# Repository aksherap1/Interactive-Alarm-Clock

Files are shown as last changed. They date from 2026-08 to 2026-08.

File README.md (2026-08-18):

# Interactive Robotic Alarm Clock

Screenshot 2026-08-17 at 5 17 38 PM

An expressive 6-DOF robotic alarm clock designed in Onshape, engineered for rapid FDM/SLA prototyping, and powered by an ESP32-S3 custom PCB. The character wakes users up using biomimetic kinematic motion and personality states prior to audio alarms.

**CAD Model:** [View Onshape 3D Assembly](https://cad.onshape.com) *(Insert Onshape Public Link)*  
**Author:** Akshera Paladhi  
**Date:** August 15, 2026  

---

## Overview & Emotional States

The robot uses physical gestures and lighting to communicate status before audio triggers:

- **Sleeping:** Head slouches forward/down, ears droop, and ambient LEDs slowly breathe with a dim, soft light.
- **Waking Up:** Head lifts smoothly, pans to face the user, and ears perk up.
- **Alarm Active:** Head aligns directly with the user, ears flap straight back, ambient LEDs pulse, and I2S audio begins.
- **Snooze:** Hitting the top snooze button causes the head to drop back into a slouch while the ears relax into rest mode.

---

## Kinematics & Motion (6-DOF)

The mechanical assembly uses daisy-chained **FeeTech SCS0009** serial micro-servos to minimize wiring harnesses across moving joints:

| Articulation Stage | DOFs | Range of Motion | Mechanical Function |
| :--- | :---: | :--- | :--- |
| **Head Base (Yaw)** | 1 | 330° | Panning rotation to scan and face user |
| **Head Pivot (Pitch/Roll)** | 1 | 180° | Nodding and expressive tilting |
| **Left Ear (Yaw + Pitch)** | 2 | 330° Yaw, 180° Pitch | Independent perking, swivel, and drooping |
| **Right Ear (Yaw + Pitch)** | 2 | 330° Yaw, 180° Pitch | Independent perking, swivel, and drooping |

---

## Design for Manufacturing & Assembly (DFM / DFA)

The enclosure splits into 9 modular parts designed for supportless 3D printing and tool standardization:
- **Modular Breakdown (9 Printed Parts):**
  1. `Clock Main Base`: 6.50" x 4.63" x 0.50" octagon with filleted corners to eliminate warping; built-in pass-through slots for wiring.
  2. `Clock Cover Base`: Flat front bezel with 3.0" circular display cutout; prints flat with zero support material.
  3. `Clear Case (Screen Lens)`: Drop-in transparent PETG protective lens.
  4. `Battery Pack Cover`: Clamping plate securing a 2x 18650 sled with two accessible fasteners.
  5. `Ears (x2)`: Dual Mickey-style ear paddles with direct servo horn mounting brackets.
  6. `Box Servos (x2)`: Keyed cutouts holding the vertical yaw servo bodies.
  7. `Three Box (x3)`: Structural rectangular housings linking the pitch/yaw servos.
  8. `Bottom Chassis`: Wide footprint housing the main vertical yaw servo to keep the center of mass low.
  9. `Bottom Chassis Cover`: Underside access plate for servicing batteries and the base servo.
- **Hardware Standardization:** Standardized on M2 machine screws (0.177" clearance pockets) paired with M2 brass heat-set inserts melted into 5.0 mm deep standoffs. The entire assembly requires only a single 1.5 mm hex driver.

---

## Electronics & Custom 2-Layer PCB

The internal board separates user-facing interfaces from high-current power stages:

### Front Side (User-Facing)
- 3.0-inch circular SPI/RGB display module
- 3x Tactile push buttons (Snooze, Alarm Set, Reset/Boot)
- WS2812B addressable RGB LEDs for diffused ambient lighting

### Back Side (Power & Logic)
- **MCU:** ESP32-S3 dual-core microcontroller
- **Power Management:** AMS1117 3.3V LDO regulator + TP4056 lithium battery charger (2x 18650 Li-ion cells)
- **Audio Stage:** MAX98357A I2S audio amplifier driving a mini speaker
- **Connectivity:** JST-PH connectors for daisy-chained servos and battery power
- **Signal Integrity:** Solid copper ground plane on Layer 2 to isolate motor noise; 4.7kΩ pull-up resistors on active-low tactile lines

---

## Engineering Calculations & Validation

### 1. Neck Tilt Servo Torque Margin
```text
Torque Equation:
  τ_req = (m * g * r) * S

Variables:
  m = 0.165 kg (Head assembly: housing, LCD, PCB, hardware)
  g = 9.81 m/s²
  r = 0.048 m (Distance to Center of Mass)
  S = 1.5 (Safety Factor)

Calculation:
  τ_req = (0.165 kg * 9.81 m/s² * 0.048 m) * 1.5
  τ_req = 0.116 N·m ≈ 1.19 kg·cm

Validation:
  FeeTech SCS0009 stall torque @ 6V = 2.30 kg·cm
  Factor of Safety (FoS) = 2.30 / 1.19 = 1.93 (Stall-free continuous operation)
Stress Equation:
  σ = (M * c) / I

Parameters:
  Applied Load = 30 N (~6.7 lbf downward impact)
  Max Bending Stress (σ) = 14.2 MPa
  PETG Yield Strength (σ_y) = 45.0 MPa

Validation:
  Factor of Safety (FoS) = 45.0 / 14.2 = 3.17 (Safe against fatigue impact)
[ Weeks 1-4: EVT / Proto ] ──> [ Weeks 5-12: EVT / Validation ] ──> [ Weeks 13-20: DVT ] ──> [ Weeks 21-26: PVT / Launch ]
  • CAD kinematic check         • Mold draft angles & bosses        • Tooling & steel molds     • First-article inspection
  • 3D print load testbench     • 1m drop testing on wood           • 100k-cycle joint life     • Work instructions & SOPs
  • 2-layer PCB layout          • Wire harness fatigue cycling      • Acoustic dampening tune   • Final packaging & release

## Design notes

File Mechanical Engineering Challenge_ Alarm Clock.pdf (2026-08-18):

Akshera Paladhi

August 15, 2026

# Mech Challenge Documentation: Alarm Clock

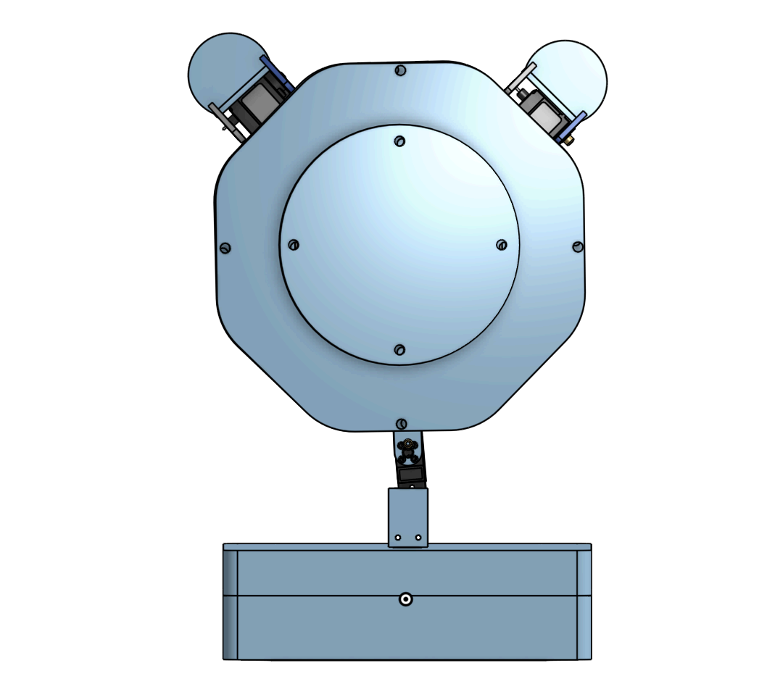
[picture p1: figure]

# Deliverables

CAD Model Link: Onshape Design (https://cad.onshape.com/documents/98c9af075805dfa337587d56/w/5debba2be09580806e3426c2/e/b373fb9812e17f7dab6772cc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)

## Design Overview & Decision Matrix

For this challenge, I wanted to turn the clock into an expressive little robot character that wakes you up using natural motion and personality before it makes somes sound.

The character has these emotional states:

1

- Sleeping: The head slouches forward/down slightly, the ears droop, and the ambient LEDs slowly breathe with a dim, soft light.
- Waking Up: The head slowly lifts up and pans smoothly to face you, and the ears perk up.
- Alarm Going Off: The head looks straight at you, the ears flap back straight, and the alarm audio begins to play.
- Snooze: When you hit the snooze button on top, the head drops back into a slouch, the ears fall backward, and it goes back to resting.

How It Moves (6 Degrees of Freedom Total)
To make the character feel alive without making the wiring a total mess, I used FeeTech SCS0009 micro servos daisy-chained together to get 6 total DOFs:
- The Head (2 DOFs):
- Spin / Yaw: The main base turns up to 330 degrees around so it can look left, right, forward, and almost all the way behind itself.
- Tilt / Nod (Pitch/Roll): Tilts side-to-side and up-and-down to show curiosity or look like it's nodding.
- The Ears (4 DOFs — 2 on each ear):
- Left Ear: Spins around 330 degrees (Yaw) and flaps front-to-back 180 degrees (Pitch).
- Right Ear: Spins around 330 degrees (Yaw) and flaps front-to-back 180 degrees (Pitch).

Why I Chose This Design?

When I started designing, I thought through three different directions:

### 1. Option 1: Just a Fixed Screen in a Box (Like an Echo Show)

- Problem: It would be super easy to 3D print and assemble, but it has zero character or physical life. It completely misses the point of the challenge.

### 2. Option 2: A Screen with 1 Simple Nodding Motor

- The Problem: Adding just one motor lets the screen tilt up and down, but that's really only one gesture (nodding). It still feels like a generic appliance with a hinge.

2

### 3. Option 3: Fully Articulated Head & Moving Ears (My Chosen Design)

- Why it won: Putting moving ears on top of a panning head gives you real character expressions (like a curious puppy or Mickey Mouse ears perking up). The main engineering challenge was making sure 6 motors did not turn into a huge mess along with the other wiring as well. By splitting the mechanical enclosure into 9 clean modular parts and designing a custom 2-layer PCB that hides all the motor connections on the back, I was able to get full 6-DOF movement while keeping the assembly clean and straightforward.

## DFM & DFA (How it’s Made & Assembled)

I broke everything into 9 3D printable parts so everything prints without any overhangs and can be put together easily like mentioned.

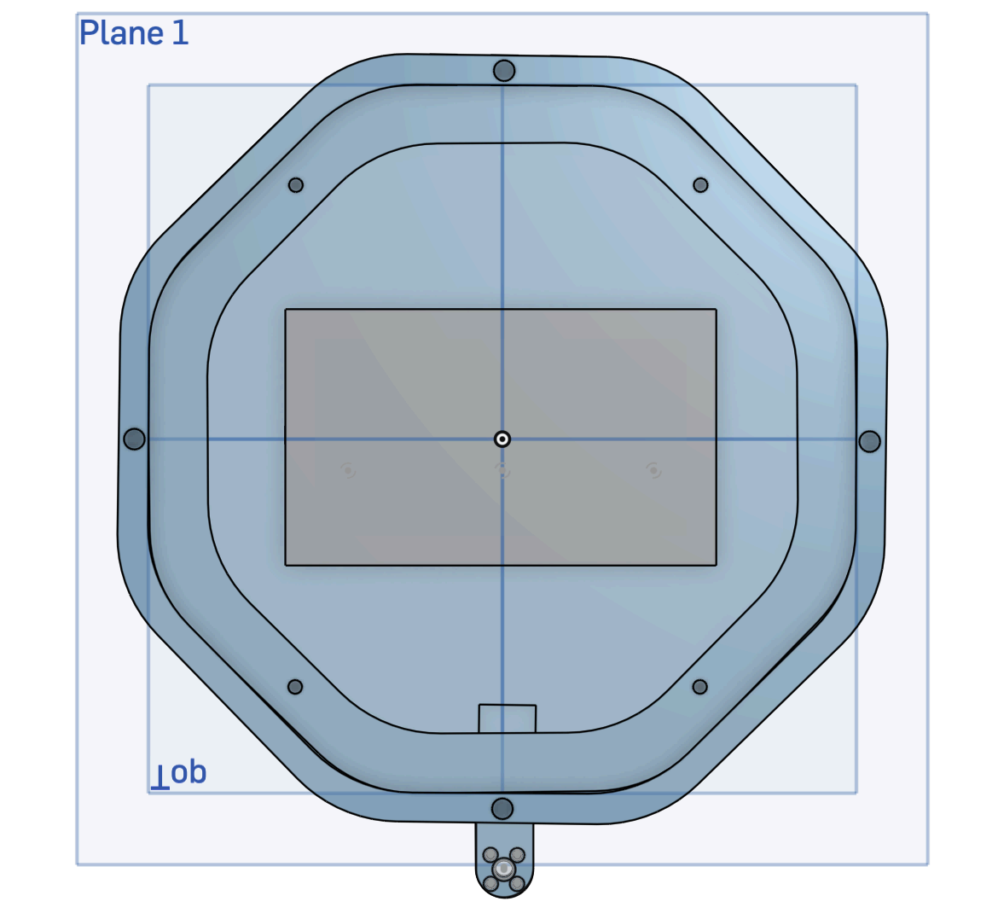
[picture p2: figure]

Clock Main Base

Sized at 6.5 inches wide, 4.63 inches deep, and 0.5 inches face thickness. I made it an octagon with filleted (rounded) corners so it prints cleanly without warping at sharp
edges.It has built-in
rectangular pass-through holes so the red and black power wires slide right through to the back of the PCB without getting pinched.

3

Clock Cover Base | Flat front bezel with a circular cutout for the 3-inch display. Prints flat with zero support material and has alignment screw holes matching the main base.

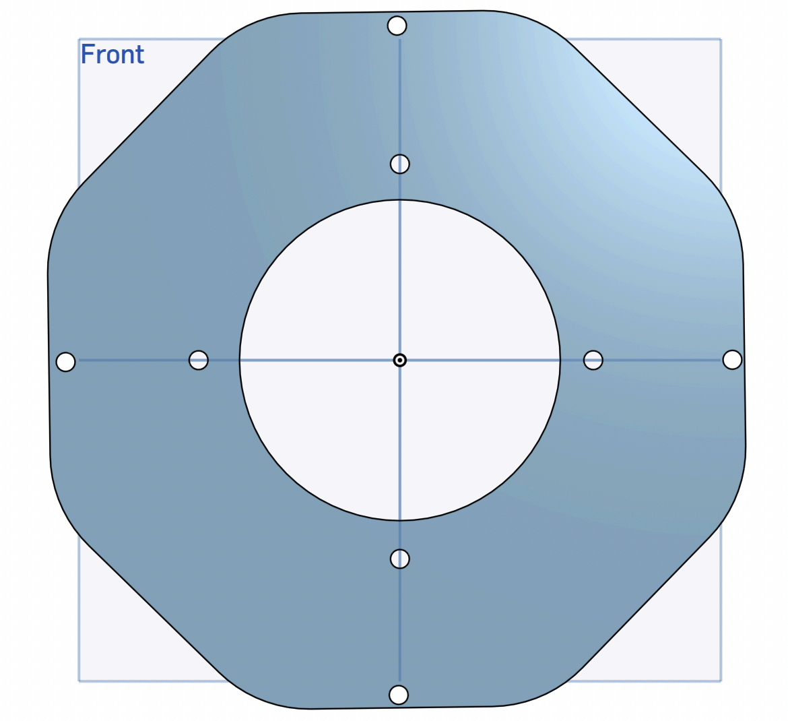
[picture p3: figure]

Clear Case (Screen Lens) | Printed out of transparent filament (Clear PETG) to protect the 3-inches LCD from dust and scratches. Drops right into the front cover bezel without needing messy adhesives.

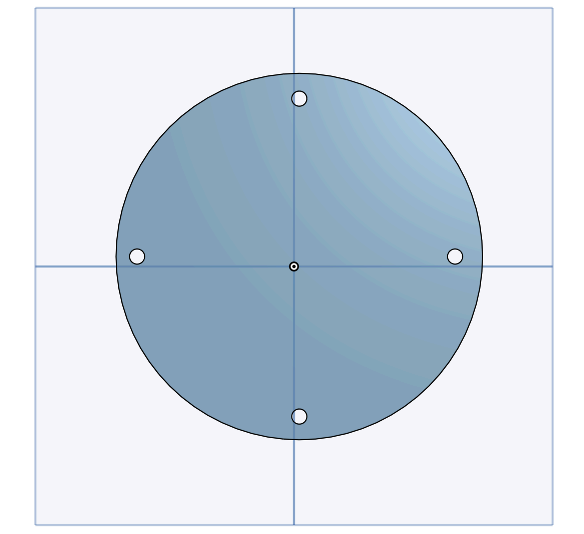
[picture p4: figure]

Battery Pack Cover | A symmetrical clamping plate that secures a standard 2x18650 battery sled inside the base using two quick screws.

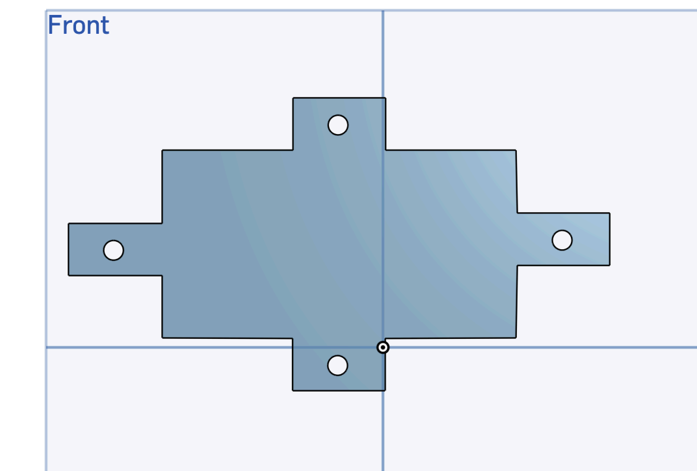
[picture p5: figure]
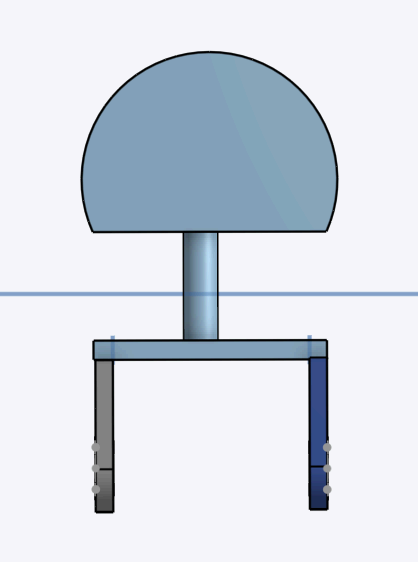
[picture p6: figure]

Two Ears (times 2) | Mickey-mouse shaped ear paddles with built-in mounting brackets. The arms attach directly to the micro servo horns so the ears can flap back and forth without extra linkage parts.

4

Two Box servos (times 2) | Specially keyed cutout that holds the FeeTech SCS0009 servo body securely.This is for the vertical yaw for the ear.

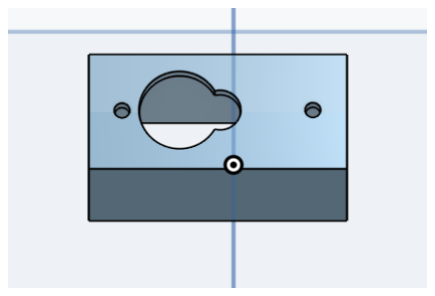
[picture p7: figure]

Three Box (times 3) | A simple rectangular housing that prints straight up without support. Also used to insert another servo in here as well.This is the vertical yaw servo can be attached to the servo that allows the two ears to flap back and forth and the head to go side to side.

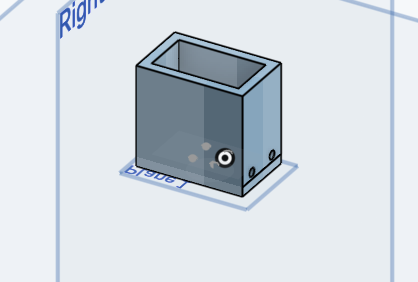
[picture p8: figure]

Bottom Part (Chassis) | Wide, sturdy bottom base that holds the main vertical yaw servo and keeps the center of mass low so the clock doesn't wobble when it turns.

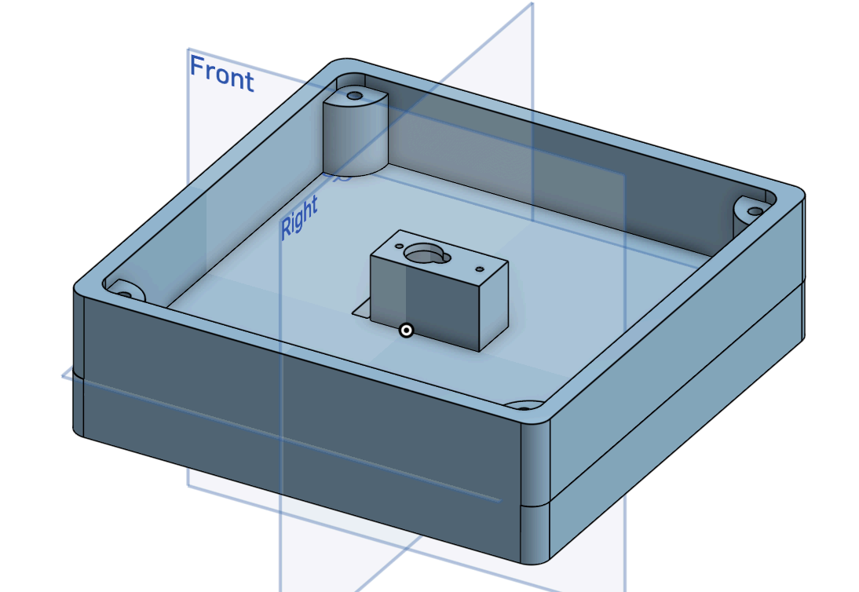
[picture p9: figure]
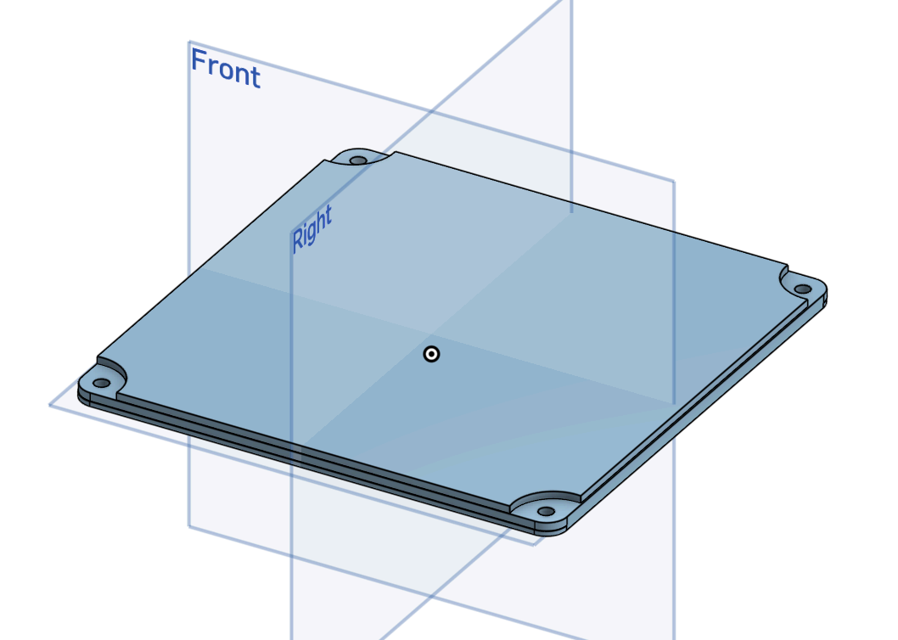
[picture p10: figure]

Bottom Part Cover | Flat plate that seals the bottom base. Screws on from the underside so you can easily access the battery and bottom servo without taking the entire head apart.

Hardware Standardization (DFA): I standardized all mounting hardware to use M2 machine screws 0.177 inches clearance pockets, 0.338 inches paired with M2 brass heat-set inserts melted into

### 5.0 mm deep standoffs.This means you only need one 1.5 hex driver

to build the whole clock, and the brass threads won't strip if

5

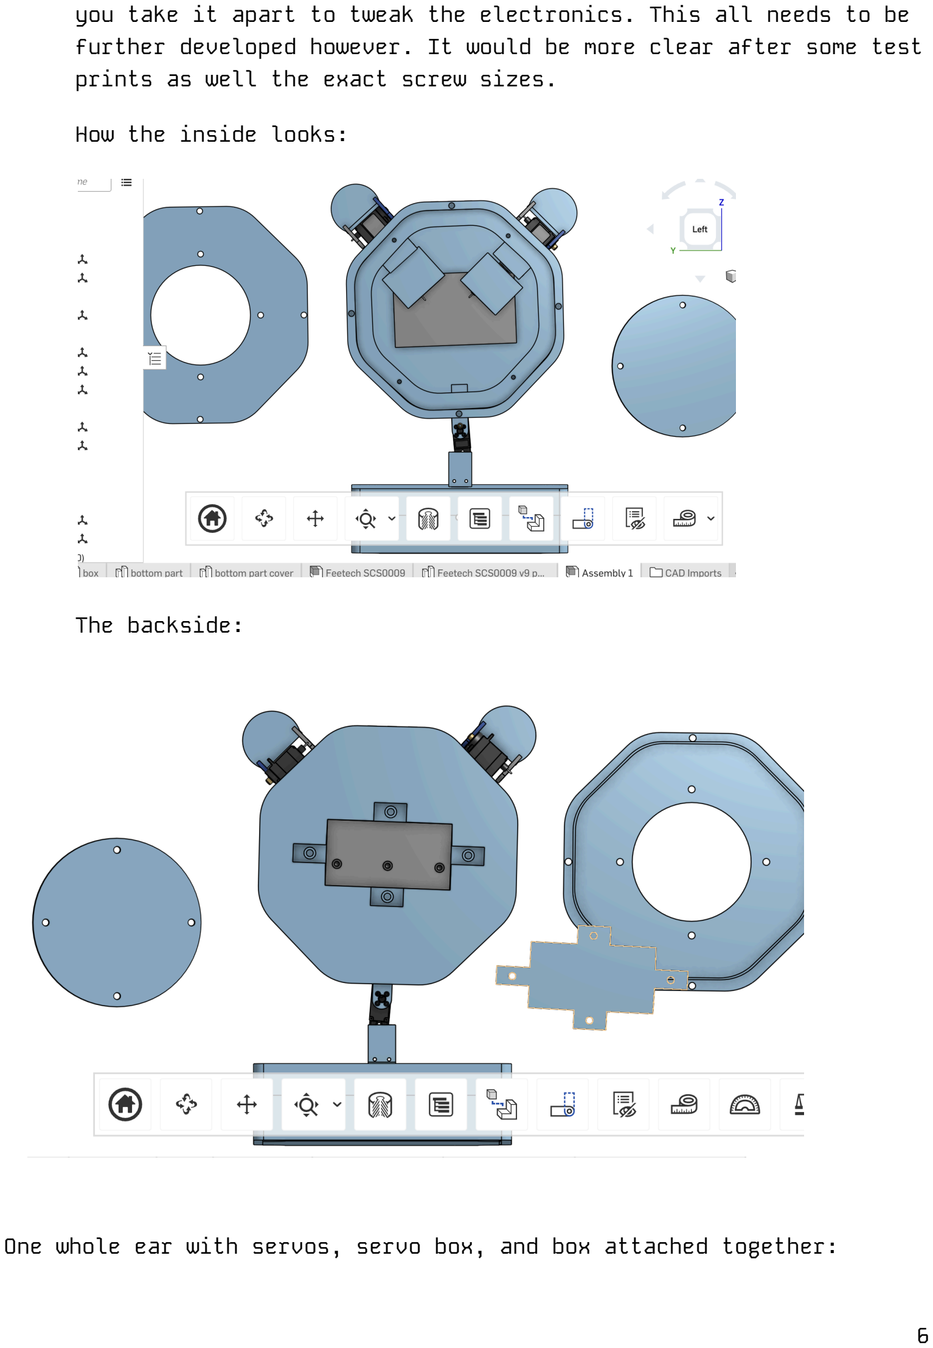
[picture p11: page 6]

you take it apart to tweak the electronics. This all needs to be further developed however. It would be more clear after some test prints as well the exact screw sizes.

How the inside looks:

The backside:

One whole ear with servos, servo box, and box attached together:

6

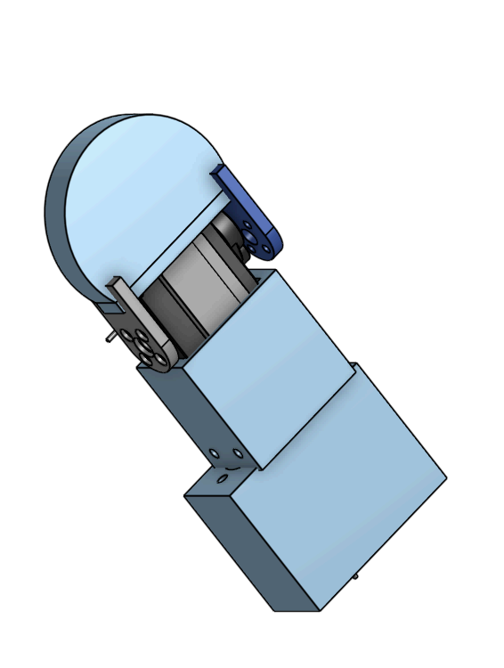
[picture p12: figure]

## Custom 2-Layer PCB Design

I put a custom 2-layer PCB inside the main base to separate the clean user controls on the front from the messy wiring and power circuitry on the back:

PCB layout:

Front Side (What User Sees)
- 3.0 Inches Circular display Screen
- 3 Tactile Push Buttons (Snooze, Alarm Set, Reset/Boot)
- WS2812B RGB LEDs for soft ambient lighting

Back Side (Internal Wiring)
- ESP32-S3 Microcontroller Module
- AMS1117 3.3V Voltage Regulator + TP4056 Battery Charger
- MAX98357A I2S Audio Amp for the speaker
- JST Connectors for daisy-chaining servos & battery pack
- 4.7kΩ Pull-Up Resistors + Power Filtering Capacitors
- Solid Copper Ground Plane to block motor electrical noise

I used 4.7kΩ pull-up resistors (tied to 3.3V) on the buttons and communication lines. When a button is pressed, it pulls the signal line to GND. This gives a reliable active-low trigger and prevents the ESP32 from glitching when the motors draw power.

7

## Engineering Math & Calculations

We need to prove the FeeTech SCS0009 servo has enough torque to lift and tilt the head without stalling:

τ = (m * g * r) * S

- Head Assembly Weight (m): Approximately 0.165 kg (Housing, LCD screen, PCB, hardware)
- Distance to Center of Mass (r): Approximately 4.8 cm/0.048 m
- Safety Factor (S) : 1.5

τ = (0.165 kg *9.81m/s^2 * 0.048 m) * 1.5 = 0.116N * m = 1.19kg * cm

Validation: The FeeTech SCS0009 provides 2.30 kg * cm of
torque at 6V. Since we only need 1.19 kg*cm, we have a Factor
of Safety of approximately 1.93, so the servo will run smooth and won't overheat.
B. Stress Check ("Snooze Slap" Test)
When someone is half-awake and smacks the top snooze button with around 30N of force which is approximately 6.7 lbs.

σ = (M*c)/I

- Maximum calculated bending stress on the pivot mounting boss is σ = 14.2 MPa
- Standard 3D-printed PETG has a yield strength of approximately 45 MPa
- Factor of Safety: 45/14.2 = 3.17 . The plastic structure will easily take repeated morning hits without cracking.
C. Motor Vibration & Heat Management
- Vibration/Acoustics: Small servos can buzz and rattle plastic shells. I would add silicone damping rings between the servo mounts and the printed boxes (Part 7) to mechanically isolate motor chatter and keep the alarm speaker sounding clear.
- Thermal Dissipation: The ESP32 and voltage regulator only pull about 2.5W on average. The cable cutouts in the back provide

8

natural airflow to keep internal temperatures below 55 degrees Celsius without the need of noisy fans.

## Material Choices

- Main Base, Covers & Chassis > PETG: Tougher and more heat-resistant than regular PLA, handles impacts from being slapped, and holds brass heat-set inserts securely without cracking.
- Clear Screen Cover (Part 3) >Transparent PETG / Acrylic: Clear and see-through to protect the LCD screen from dust and scratches.
- Joint Boxes & Brackets >Nylon / PETG: Low-friction and wear-resistant so rotating joints do not wear down or bind over time.
- Vibration Dampers > Molded Silicone Rubber: Soft rubber grommets that absorb motor buzzing and gear vibration.

## Manufacturing Notes & Tolerances (GD&T)

When sending the Clock Main Base (Image 1) to a machine shop or manufacturer,put emphasis on surfaces matter the most and how accurate the cuts need to be:

- What it is made of & how it gets made:
- For the working prototype, it gets 3D printed out of PETG.
- For real mass production, it gets plastic injection molded out of ABS or PETG.
- The Main Flat Mounting Face (Datum A): The back mounting surface must be flat within 0.002 inches so the front cover and internal mounts sit completely flush without wobbling.
- The Center Servo Pivot Hole (Datum B): The main pivot hole needs a snug fit 0.472 inches with a +0.001 / -0.000 inches tolerance) so the servo spline slides in tight without slipping or binding.
- The M2 Screw Holes: The screw hole center positions have a true position tolerance of 0.003 inch relative to Datum A and Datum B so the screws always line up with the brass heat-set inserts.
- Main Face Thickness: The main front wall thickness is maintained at 0.500 inches +/- 0.005 inches (along with the overall 6.50

9

inches width and 3.63 inches depth) so the structural shell holds its shape without sinking or warping.

## Product Launch Roadmap & Engineering Tasks

If I were leading the mechanical design from day one to the launch date, here is the timeline and the main engineering tasks (tickets) to get it built and shipped:
Phase 1: Concept & Prototyping (Weeks 1 to 4)
- Task 1: Finish the 3D model in CAD and check that the head and ears can turn without bumping into each other.
- Task 2: 3D print a quick test rig to test the micro servos under real weight and make sure they don't stall.
- Task 3: Size the custom 2-layer PCB layout so all the electronics fit cleanly inside the head.
Phase 2: Engineering Validation (EVT) (Weeks 5 to 12)
- Task 1: Add draft angles (slight slopes on the walls) and screw bosses into the CAD files so the parts can be injection molded.
- Task 2: Drop-test the 3D-printed body from a desk height of 1 meter onto wood to make sure the plastic doesn't snap.
- Task 3: Run the head back and forth continuously to verify that internal wires don't twist, rub, or wear out.
Phase 3: Design Validation (DVT) (Weeks 13 to 20)
- Task 1: Send the final 2D drawings to the factory to start cutting the steel injection molds.
- Task 2: Run long-term reliability tests on the ears and neck joints (moving them about or more than 100,000 times to check for wear).
- Task 3: Adjust the rubber dampening around the motors so the alarm speaker sounds clear without making the plastic shell rattle.
Phase 4: Production & Launch (PVT) (Weeks 21 to 26)
- Task 1: Inspect the first real batch of molded plastic parts from the factory to make sure dimensions match the drawings.

10

- Task 2: Set up the assembly line steps and write a simple assembly guide for the factory workers.
- Task 3: Run final packaging drop tests, box the units up, and launch the product.

## Future Upgrades & Next Steps

Add a Center Slip-Ring: Right now the head turns 330 degrees so the wires don't wrap up. Adding a small 4-wire slip ring down the center shaft would let the head spin a full continuous 360 degrees.

Capacitive Touch Snooze: Instead of a mechanical push button on top, put a capacitive touch sensor on the inside of the top shell so you can tap anywhere on the head to snooze. This way a user can pet the alarm clock and it can create that more interactive feature.

Organic Motion Curves: Program smooth S-curve bezier acceleration in C + on the ESP32 so the head and ears accelerate and slow down gently like a real living character just like the PIXAR lamp that was created as well.

11

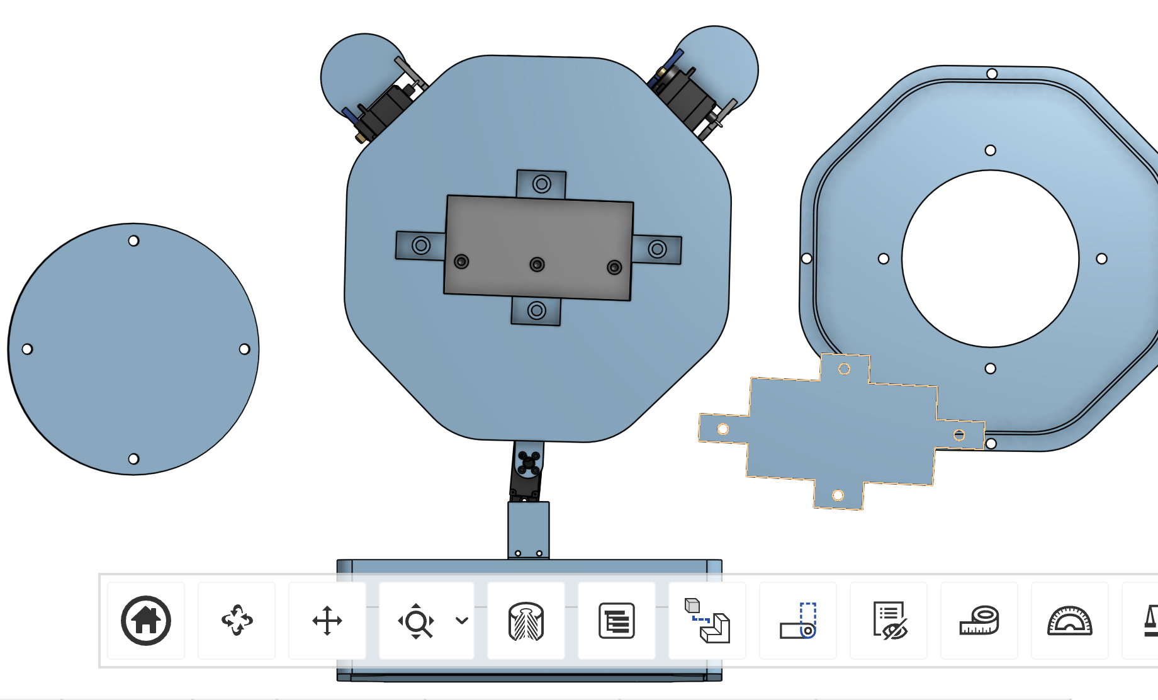
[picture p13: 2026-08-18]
Screenshot 2026-08-15 at 1.11.09 AM.png

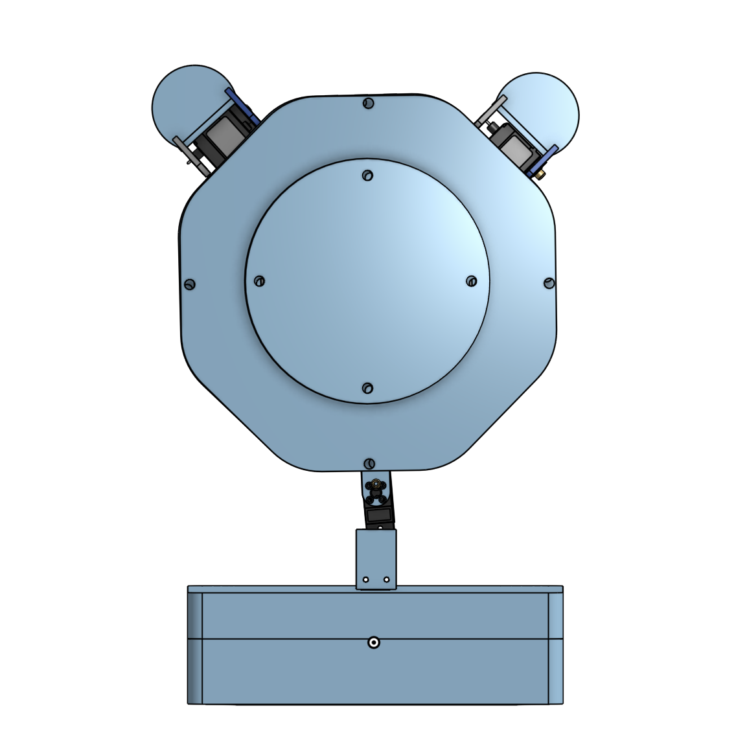
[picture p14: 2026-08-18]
Screenshot 2026-08-17 at 5.17.38 PM.png

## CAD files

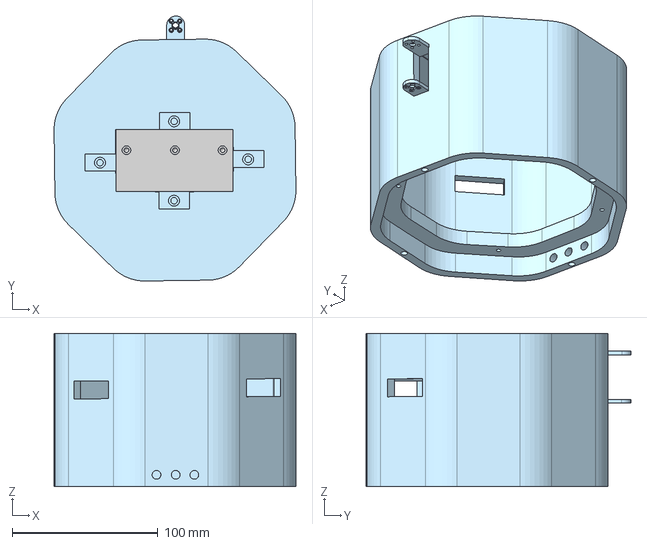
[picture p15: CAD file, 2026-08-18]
clock main base.step
165.7 x 181.5 x 104.9 mm

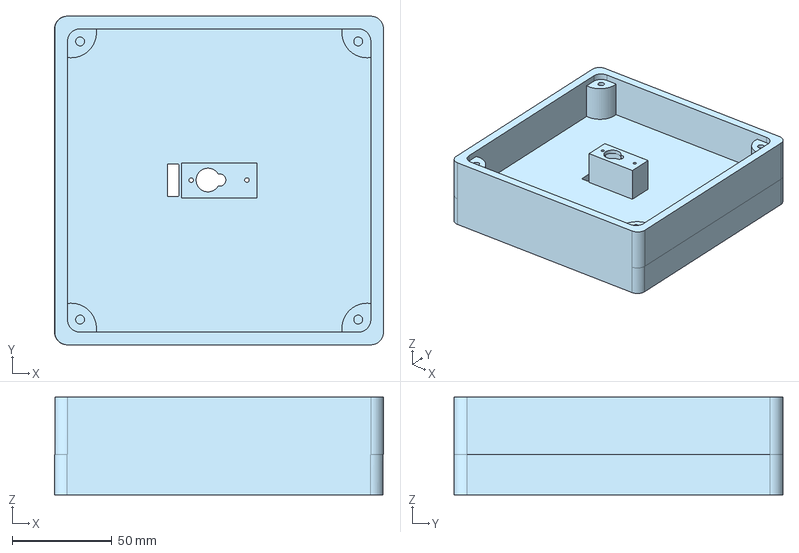
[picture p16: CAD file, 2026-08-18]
bottom part - Part 1.step
165.3 x 165.1 x 49.0 mm

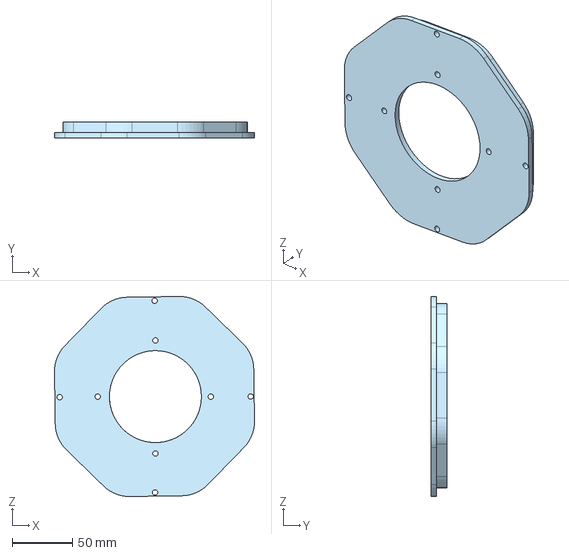
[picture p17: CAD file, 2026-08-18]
clock cover base - Part 1.step
165.7 x 12.9 x 165.7 mm

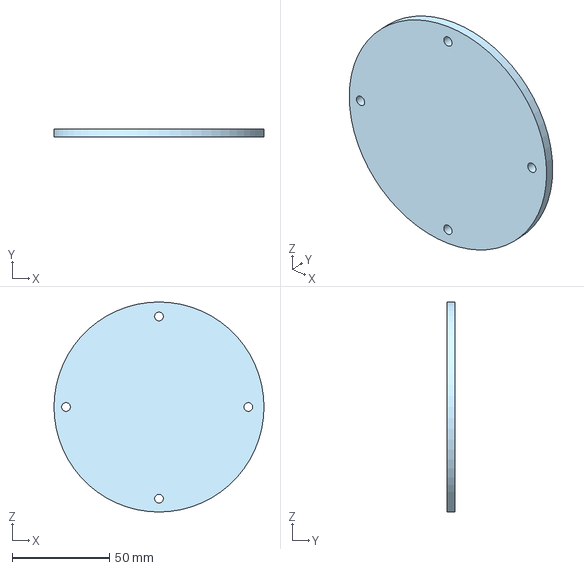
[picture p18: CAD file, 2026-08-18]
clear case - Part 1.step
108.0 x 4.29 x 107.9 mm

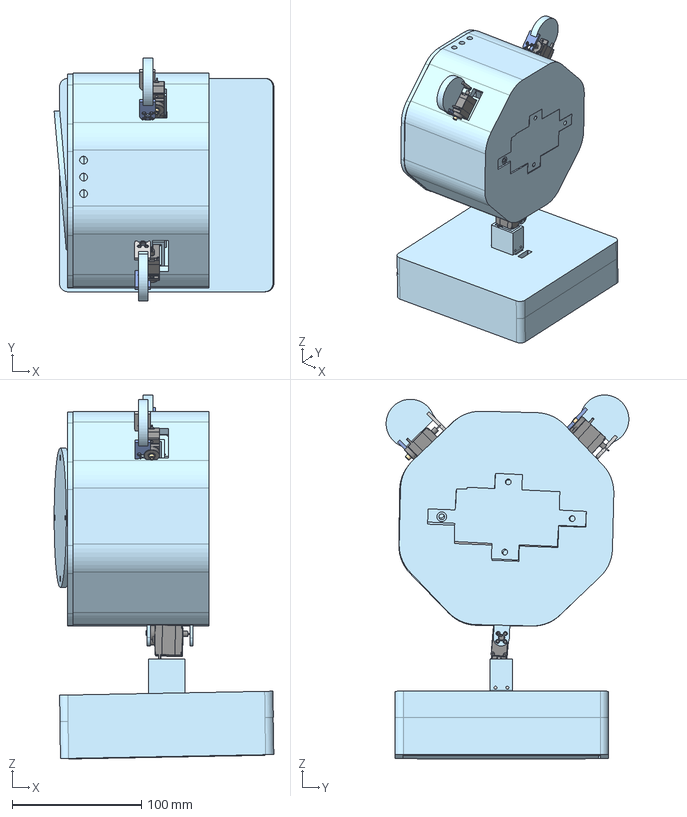
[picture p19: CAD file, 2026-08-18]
Interactive Alarm Clock.step
170.0 x 187.8 x 281.6 mm
Cap x 6
Horn x 6
Base x 6
servo screw:1__Body1 x 6

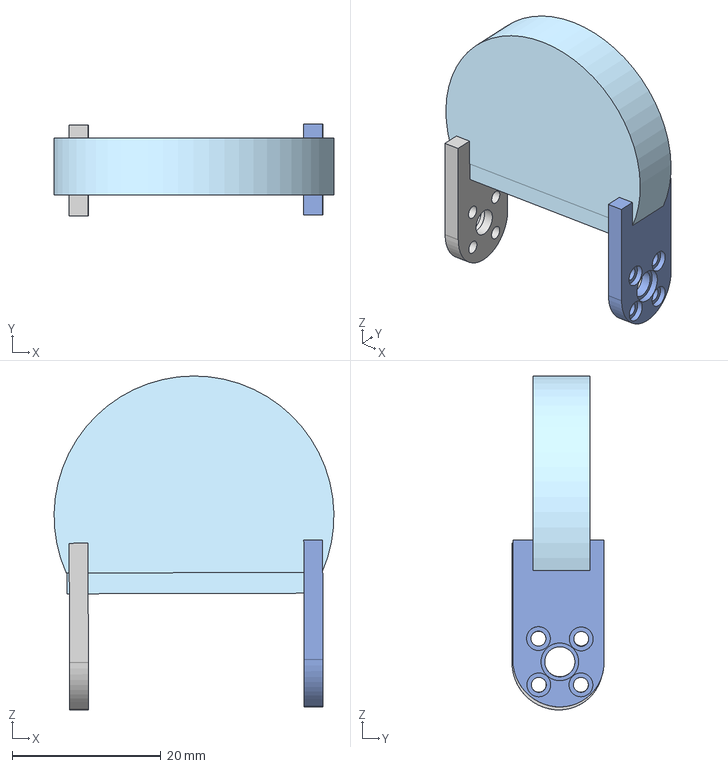
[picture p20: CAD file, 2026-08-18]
ears.step
37.6 x 12.4 x 44.8 mm

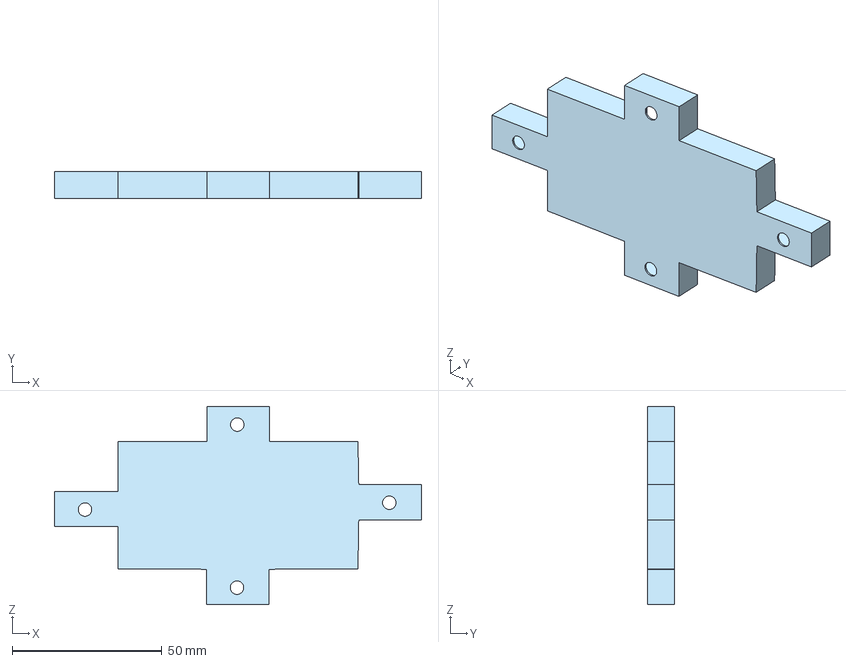
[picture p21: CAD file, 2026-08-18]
battery pack cover - Part 1.step
122.4 x 9.09 x 66.2 mm

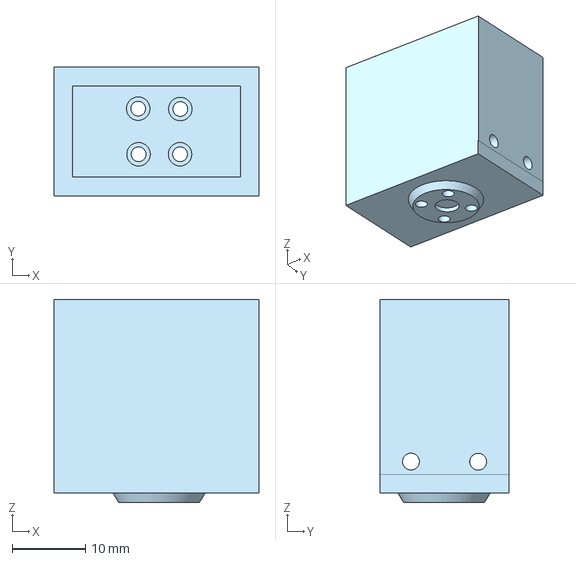
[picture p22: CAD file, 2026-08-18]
box - Part 1.step
27.9 x 17.5 x 27.7 mm

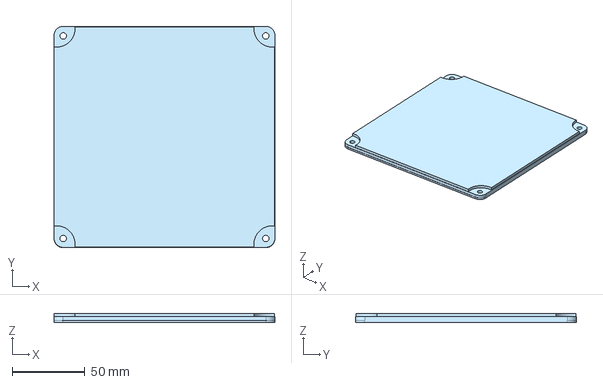
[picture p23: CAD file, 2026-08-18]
bottom part cover - Part 1.step
152.4 x 152.7 x 6.35 mm

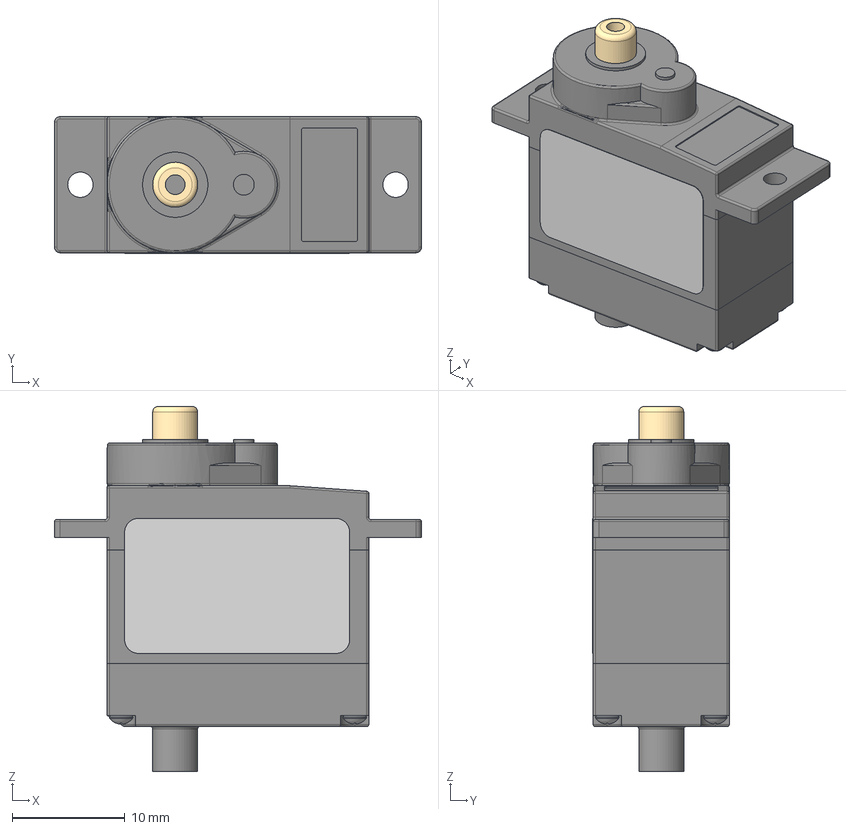
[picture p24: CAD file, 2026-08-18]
Feetech SCS0009 v9.step
32.6 x 12.1 x 32.5 mm
91772A071_NO THREADS_Passivated 18-8 Stainless Steel Pan Head Phillip s Screw x 4

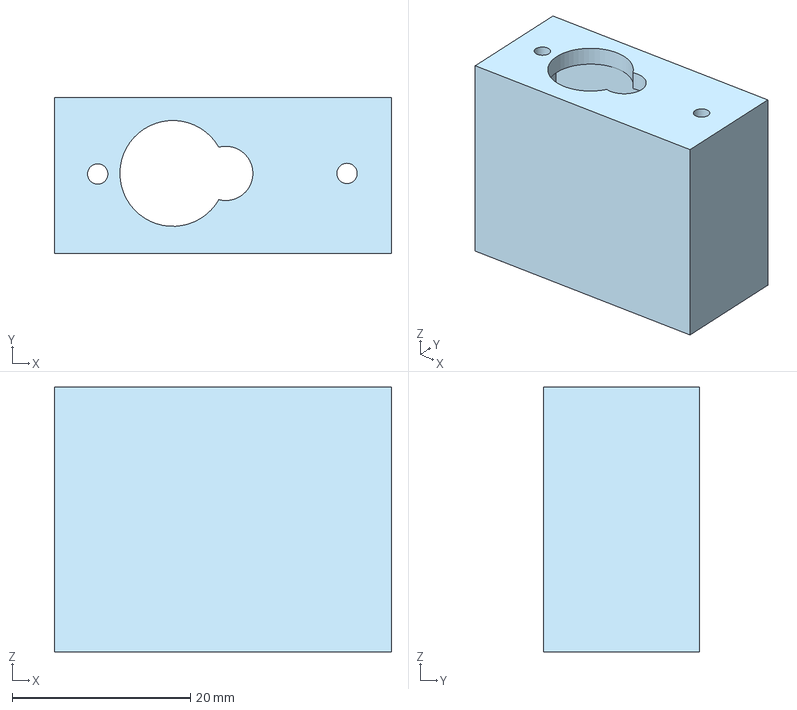
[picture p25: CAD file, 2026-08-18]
box servo - Part 1.step
37.8 x 17.5 x 29.7 mm
